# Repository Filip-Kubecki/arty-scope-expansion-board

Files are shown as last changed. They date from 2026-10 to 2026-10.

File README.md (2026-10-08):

<!-- markdownlint-disable MD013 MD060 -->

# Two-Channel Scope Expansion Board for Arty A7

KiCad design of an analog shield for the Digilent Arty A7 100T. The board plugs into the Pmod connectors and, together with the FPGA design, forms a two-channel digital oscilloscope.

<p align="center">
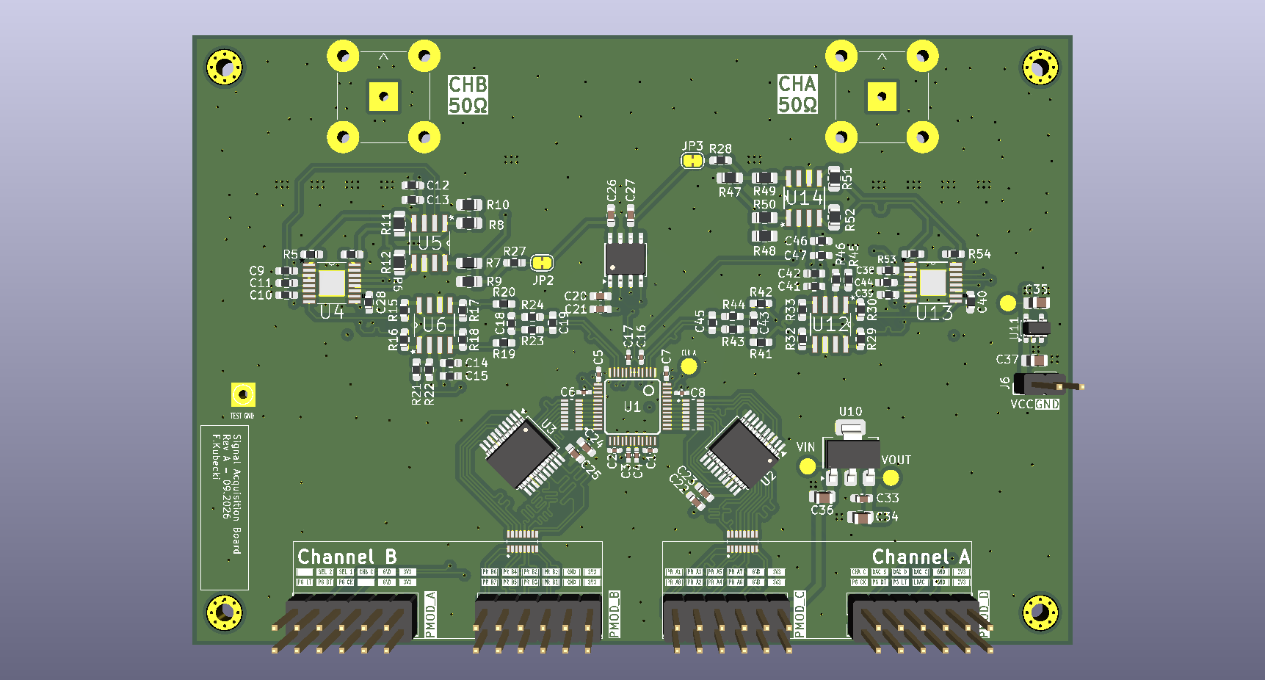
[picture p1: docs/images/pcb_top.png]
3D render of the board
  
</p>

## Hardware

- **Host board:** Digilent Arty A7 100T (connected via Pmod headers)
- **ADC:** AD9288-100 (dual 8-bit, 100 MS/s)
- **PGA:** AD8370 (variable gain amplifier)
- **DAC:** MCP4822 (DC offset)
- **EDA:** KiCad 10.0

## Related repositories

- FPGA design: [arty-scope-hdl](https://github.com/Filip-Kubecki/arty-scope-hdl)

## Repository structure

```
hardware/      KiCad project (schematic, PCB, project-local libraries)
  libs/        custom symbols, footprints and 3D models
docs/          notes, datasheets, pinout and block diagram
fab/           fabrication outputs - Gerbers, drill, BOM, pick&place (git-ignored, see Releases)
```

## Getting started

Clone the repository:

```bash
git clone https://github.com/Filip-Kubecki/arty-scope-expansion-board.git
cd arty-scope-expansion-board
```

Open `hardware/arty-scope-expansion-board.kicad_pro` in KiCad. Project-local libraries are referenced through `sym-lib-table` and `fp-lib-table`, so no manual setup is needed.

### Generating fabrication files

Fabrication outputs are not stored in git. To generate them:

1. Open the PCB in the PCB Editor.
2. Run **File → Fabrication Outputs → Gerbers** and **Drill Files**, writing to `fab/`.
3. Export BOM and placement files from the Schematic and PCB Editors if needed.

Ready-to-order packages for tagged versions are attached to [GitHub Releases](https://github.com/Filip-Kubecki/arty-scope-expansion-board/releases).

## Status

Work in progress.

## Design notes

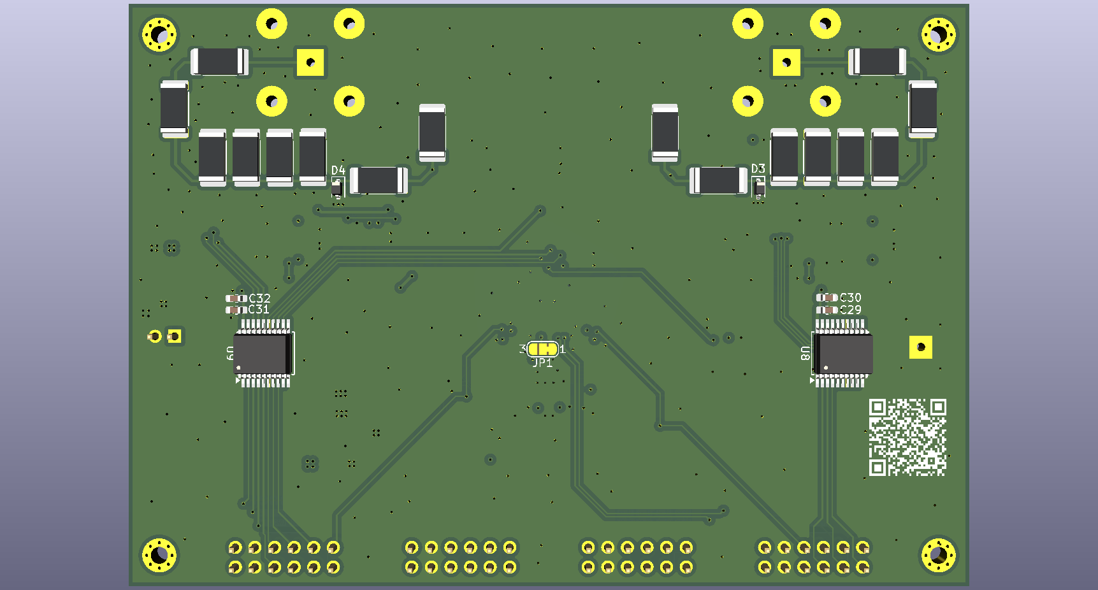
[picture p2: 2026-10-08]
docs/images/pcb_bottom.png

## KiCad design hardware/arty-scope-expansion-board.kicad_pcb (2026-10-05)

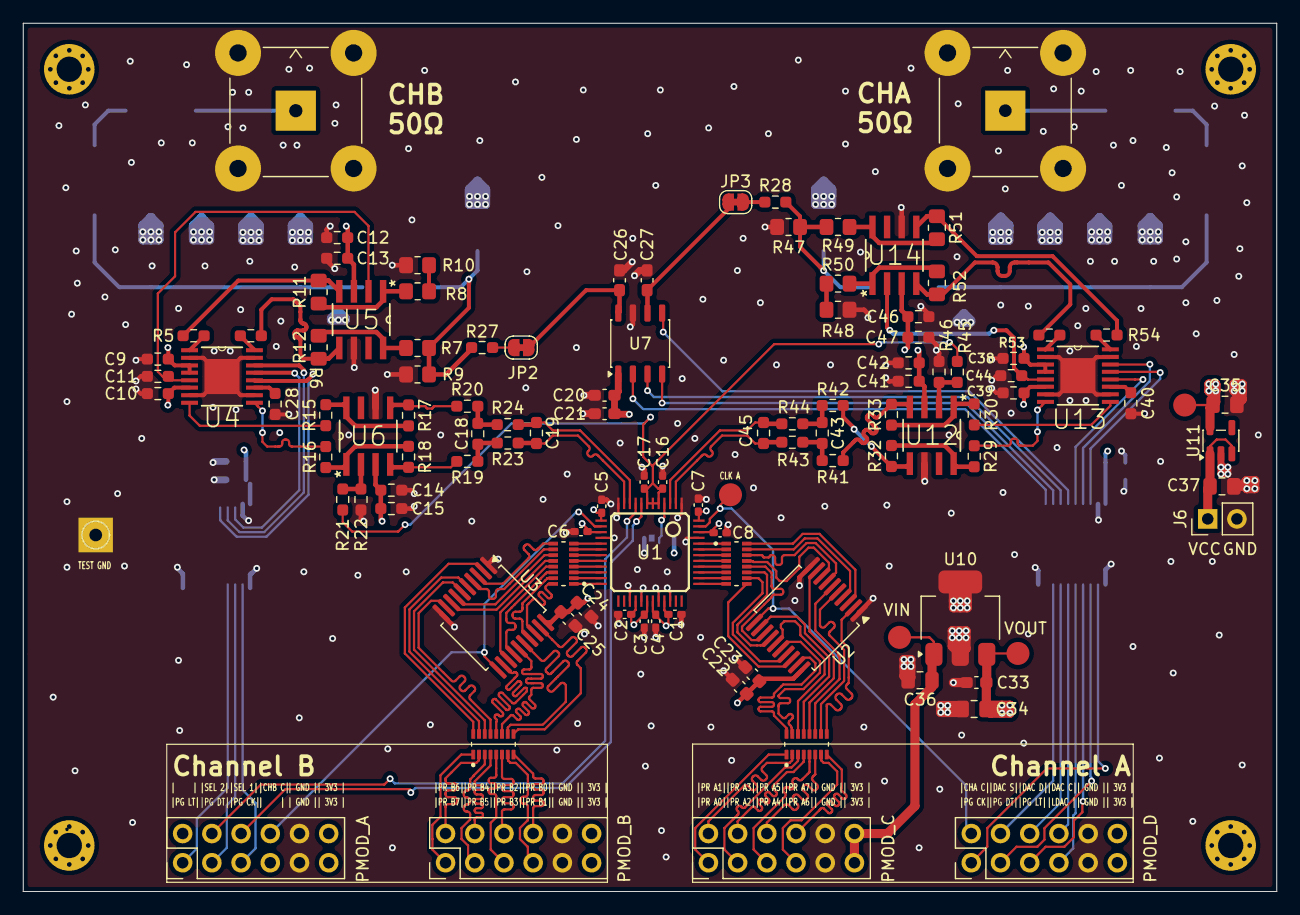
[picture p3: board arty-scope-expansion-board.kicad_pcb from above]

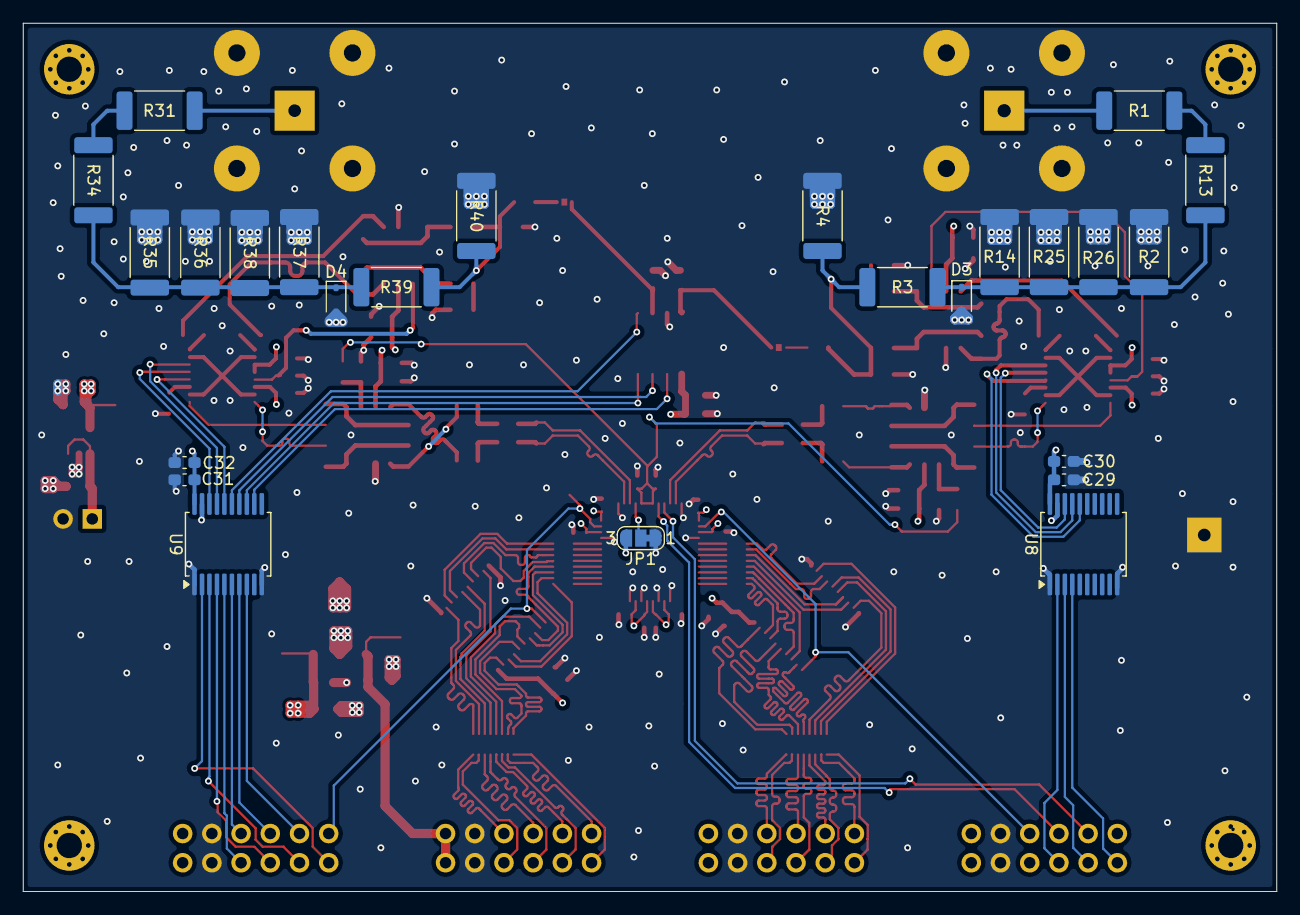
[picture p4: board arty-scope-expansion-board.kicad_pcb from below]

Board: 4 copper layers, 109.0 x 75.5 mm, 131 parts (25 on the bottom side), 147 nets.

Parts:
C1, C2, C3, C4, C5, C6, C7, C8, C16, C17: 100n; C_0402_1005Metric_Pad0.74x0.62mm_HandSolder
C9, C13, C14, C38, C41, C46: 100n; R_0603_1608Metric_Pad0.98x0.95mm_HandSolder
C10, C11, C28, C39, C40, C44: 1n; R_0603_1608Metric_Pad0.98x0.95mm_HandSolder
C12, C15, C42, C47: 10u; R_0603_1608Metric_Pad0.98x0.95mm_HandSolder
C18, C43: 47p; R_0603_1608Metric_Pad0.98x0.95mm_HandSolder
C19, C45: 10p; R_0603_1608Metric_Pad0.98x0.95mm_HandSolder
C20, C23, C25, C29, C31, C33: 100n; C_0603_1608Metric_Pad1.08x0.95mm_HandSolder
C21, C22, C24, C30, C32: 10u; C_0603_1608Metric_Pad1.08x0.95mm_HandSolder
C26, C27: 1n; C_0603_1608Metric_Pad1.08x0.95mm_HandSolder
C34, C35, C37: 1u; C_0805_2012Metric_Pad1.18x1.45mm_HandSolder
C36: 4u7; C_0805_2012Metric_Pad1.18x1.45mm_HandSolder
D3, D4: CDSOD323-T24C; D_SOD-323
J1: PMOD_A; PinHeader_2x06_P2.54mm_Vertical
J2: PMOD_B; PinHeader_2x06_P2.54mm_Vertical
J3: PMOD_C; PinHeader_2x06_P2.54mm_Vertical
J4: PMOD_D; PinHeader_2x06_P2.54mm_Vertical
J5, J7: Conn_Coaxial; BNC_TEConnectivity_1478035_Horizontal
J6: Conn_01x02_Pin; PinHeader_1x02_P2.54mm_Vertical
JP1: DFS Select; SolderJumper-3_P1.3mm_Bridged12_RoundedPad1.0x1.5mm_NumberL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
JP2, JP3: Jumper_2_Bridged; SolderJumper-2_P1.3mm_Bridged_RoundedPad1.0x1.5mm
R1, R13, R31, R34: 11; R_2512_6332Metric_Pad1.40x3.35mm_HandSolder
R2, R14, R25, R26, R35, R36, R37, R38: 222; R_2512_6332Metric_Pad1.40x3.35mm_HandSolder
R3, R39: 499; R_2512_6332Metric_Pad1.40x3.35mm_HandSolder
R4, R40: 55.6; R_2512_6332Metric_Pad1.40x3.35mm_HandSolder
R5, R6, R19, R20, R41, R42, R53, R54: 100; R_0603_1608Metric_Pad0.98x0.95mm_HandSolder
R7, R8, R11, R12, R49, R50, R51, R52: 499; R_0805_2012Metric_Pad1.20x1.40mm_HandSolder
R9, R47: 55.6; R_0805_2012Metric_Pad1.20x1.40mm_HandSolder
R10, R48: 27.8; R_0805_2012Metric_Pad1.20x1.40mm_HandSolder
R15, R16, R17, R18, R29, R30, R32, R33: 499; R_0603_1608Metric_Pad0.98x0.95mm_HandSolder
R21, R45: 2.61k; R_0603_1608Metric_Pad0.98x0.95mm_HandSolder
R22, R46: 10k; R_0603_1608Metric_Pad0.98x0.95mm_HandSolder
R23, R24, R43, R44: 49.9; R_0603_1608Metric_Pad0.98x0.95mm_HandSolder
R27, R28: 20k; R_0603_1608Metric_Pad0.98x0.95mm_HandSolder
R_Pack_ADC_Side_A1: 51; RESCAXE50P380X160X55-16N
R_Pack_ADC_Side_B1: 51; RESCAXE50P380X160X55-16N
R_Pack_PMOD_Side_A1: 51; RESCAXE50P380X160X55-16N
R_Pack_PMOD_Side_B1: 51; RESCAXE50P380X160X55-16N
U1: AD9288; LQFP48
U2, U3: 74LS374; SSOP-20_5.3x7.2mm_P0.65mm
U4, U13: AD8370AREZ-RL7; SOP65P640X120-17N
U5, U6, U12, U14: AD8132ARZ; SOIC127P600X175-8N
U7: MCP4822; JEITA_SOIC-8_3.9x4.9mm_P1.27mm
U8, U9: 74AHCT541; SSOP-20_5.3x7.2mm_P0.65mm
U10: MCP1826S; SOT-223-3_TabPin2
U11: MIC5504-3.3YM5; SOT-23-5

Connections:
+3.3VCC: C1.1, C2.1, C3.1, C4.1, C5.1, C6.1, C7.1, C8.1, C22.1, C23.1, C24.1, C25.1, C33.1, C34.1, JP1.3 (B), U1.13 (VD@1), U1.15 (VDD@1), U1.28 (VDD@2), U1.30 (VD@2), U1.31 (VD@3), U1.33 (VDD@3), U1.46 (VDD@4), U1.48 (VD@4), U2.20 (VCC), U3.20 (VCC), U10.3 (VO)
+5VCC: C9.2, C10.2, C12.2, C13.2, C14.2, C15.2, C20.2, C21.2, C29.2, C30.2, C31.2, C32.2, C35.1, C38.2, C39.2, C41.2, C42.2, C46.2, C47.2, U4.3 (VCCI), U4.4 (PWUP), U4.6 (VCCO_2), U5.3 (V+), U6.3 (V+), U7.1 (Vdd), U8.20 (VCC), U9.20 (VCC), U11.5 (VOUT), U12.3 (V+), U13.3 (VCCI), U13.4 (PWUP), U13.6 (VCCO_2), U14.3 (V+)
/Root/ADC_DATA_A0: R_Pack_ADC_Side_A1.8 (R8.1), U1.37 (D0A)
/Root/ADC_DATA_A1: R_Pack_ADC_Side_A1.7 (R7.1), U1.38 (D1A)
/Root/ADC_DATA_A2: R_Pack_ADC_Side_A1.6 (R6.1), U1.39 (D2A)
/Root/ADC_DATA_A3: R_Pack_ADC_Side_A1.5 (R5.1), U1.40 (D3A)
/Root/ADC_DATA_A4: R_Pack_ADC_Side_A1.4 (R4.1), U1.41 (D4A)
/Root/ADC_DATA_A5: R_Pack_ADC_Side_A1.3 (R3.1), U1.42 (D5A)
/Root/ADC_DATA_A6: R_Pack_ADC_Side_A1.2 (R2.1), U1.43 (D6A)
/Root/ADC_DATA_A7: R_Pack_ADC_Side_A1.1 (R1.1), U1.44 (D7A)
/Root/ADC_DATA_B0: R_Pack_ADC_Side_B1.1 (R1.1), U1.24 (D0B)
/Root/ADC_DATA_B1: R_Pack_ADC_Side_B1.2 (R2.1), U1.23 (D1B)
/Root/ADC_DATA_B2: R_Pack_ADC_Side_B1.3 (R3.1), U1.22 (D2B)
/Root/ADC_DATA_B3: R_Pack_ADC_Side_B1.4 (R4.1), U1.21 (D3B)
/Root/ADC_DATA_B4: R_Pack_ADC_Side_B1.5 (R5.1), U1.20 (D4B)
/Root/ADC_DATA_B5: R_Pack_ADC_Side_B1.6 (R6.1), U1.19 (D5B)
/Root/ADC_DATA_B6: R_Pack_ADC_Side_B1.7 (R7.1), U1.18 (D6B)
/Root/ADC_DATA_B7: R_Pack_ADC_Side_B1.8 (R8.1), U1.17 (D7B)
/Root/DFLOP_ADC_DATA_A0: R_Pack_ADC_Side_A1.9 (R8.2), U2.18 (D7)
/Root/DFLOP_ADC_DATA_A1: R_Pack_ADC_Side_A1.10 (R7.2), U2.17 (D6)
/Root/DFLOP_ADC_DATA_A2: R_Pack_ADC_Side_A1.11 (R6.2), U2.14 (D5)
/Root/DFLOP_ADC_DATA_A3: R_Pack_ADC_Side_A1.12 (R5.2), U2.13 (D4)
/Root/DFLOP_ADC_DATA_A4: R_Pack_ADC_Side_A1.13 (R4.2), U2.8 (D3)
/Root/DFLOP_ADC_DATA_A5: R_Pack_ADC_Side_A1.14 (R3.2), U2.7 (D2)
/Root/DFLOP_ADC_DATA_A6: R_Pack_ADC_Side_A1.15 (R2.2), U2.4 (D1)
/Root/DFLOP_ADC_DATA_A7: R_Pack_ADC_Side_A1.16 (R1.2), U2.3 (D0)
/Root/DFLOP_ADC_DATA_B0: R_Pack_ADC_Side_B1.16 (R1.2), U3.18 (D7)
/Root/DFLOP_ADC_DATA_B1: R_Pack_ADC_Side_B1.15 (R2.2), U3.17 (D6)
/Root/DFLOP_ADC_DATA_B2: R_Pack_ADC_Side_B1.14 (R3.2), U3.14 (D5)
/Root/DFLOP_ADC_DATA_B3: R_Pack_ADC_Side_B1.13 (R4.2), U3.13 (D4)
/Root/DFLOP_ADC_DATA_B4: R_Pack_ADC_Side_B1.12 (R5.2), U3.8 (D3)
/Root/DFLOP_ADC_DATA_B5: R_Pack_ADC_Side_B1.11 (R6.2), U3.7 (D2)
/Root/DFLOP_ADC_DATA_B6: R_Pack_ADC_Side_B1.10 (R7.2), U3.4 (D1)
/Root/DFLOP_ADC_DATA_B7: R_Pack_ADC_Side_B1.9 (R8.2), U3.3 (D0)
/Root/DFLOP_PMOD_DATA_A0: R_Pack_PMOD_Side_A1.16 (R1.2), U2.19 (O7)
/Root/DFLOP_PMOD_DATA_A1: R_Pack_PMOD_Side_A1.15 (R2.2), U2.16 (O6)
/Root/DFLOP_PMOD_DATA_A2: R_Pack_PMOD_Side_A1.14 (R3.2), U2.15 (O5)
/Root/DFLOP_PMOD_DATA_A3: R_Pack_PMOD_Side_A1.13 (R4.2), U2.12 (O4)
/Root/DFLOP_PMOD_DATA_A4: R_Pack_PMOD_Side_A1.12 (R5.2), U2.9 (O3)
/Root/DFLOP_PMOD_DATA_A5: R_Pack_PMOD_Side_A1.11 (R6.2), U2.6 (O2)
/Root/DFLOP_PMOD_DATA_A6: R_Pack_PMOD_Side_A1.10 (R7.2), U2.5 (O1)
/Root/DFLOP_PMOD_DATA_A7: R_Pack_PMOD_Side_A1.9 (R8.2), U2.2 (O0)
/Root/DFLOP_PMOD_DATA_B0: R_Pack_PMOD_Side_B1.9 (R8.2), U3.19 (O7)
/Root/DFLOP_PMOD_DATA_B1: R_Pack_PMOD_Side_B1.10 (R7.2), U3.16 (O6)
/Root/DFLOP_PMOD_DATA_B2: R_Pack_PMOD_Side_B1.11 (R6.2), U3.15 (O5)
/Root/DFLOP_PMOD_DATA_B3: R_Pack_PMOD_Side_B1.12 (R5.2), U3.12 (O4)
/Root/DFLOP_PMOD_DATA_B4: R_Pack_PMOD_Side_B1.13 (R4.2), U3.9 (O3)
/Root/DFLOP_PMOD_DATA_B5: R_Pack_PMOD_Side_B1.14 (R3.2), U3.6 (O2)
/Root/DFLOP_PMOD_DATA_B6: R_Pack_PMOD_Side_B1.15 (R2.2), U3.5 (O1)
/Root/DFLOP_PMOD_DATA_B7: R_Pack_PMOD_Side_B1.16 (R1.2), U3.2 (O0)
/Root/PMOD_DATA_A0: J3.1, R_Pack_PMOD_Side_A1.1 (R1.1)
/Root/PMOD_DATA_A1: J3.2, R_Pack_PMOD_Side_A1.2 (R2.1)
/Root/PMOD_DATA_A2: J3.3, R_Pack_PMOD_Side_A1.3 (R3.1)
/Root/PMOD_DATA_A3: J3.4, R_Pack_PMOD_Side_A1.4 (R4.1)
/Root/PMOD_DATA_A4: J3.5, R_Pack_PMOD_Side_A1.5 (R5.1)
/Root/PMOD_DATA_A5: J3.6, R_Pack_PMOD_Side_A1.6 (R6.1)
/Root/PMOD_DATA_A6: J3.7, R_Pack_PMOD_Side_A1.7 (R7.1)
/Root/PMOD_DATA_A7: J3.8, R_Pack_PMOD_Side_A1.8 (R8.1)
/Root/PMOD_DATA_B0: J2.8, R_Pack_PMOD_Side_B1.8 (R8.1)
/Root/PMOD_DATA_B1: J2.7, R_Pack_PMOD_Side_B1.7 (R7.1)
/Root/PMOD_DATA_B2: J2.6, R_Pack_PMOD_Side_B1.6 (R6.1)
/Root/PMOD_DATA_B3: J2.5, R_Pack_PMOD_Side_B1.5 (R5.1)
/Root/PMOD_DATA_B4: J2.4, R_Pack_PMOD_Side_B1.4 (R4.1)
/Root/PMOD_DATA_B5: J2.3, R_Pack_PMOD_Side_B1.3 (R3.1)
/Root/PMOD_DATA_B6: J2.2, R_Pack_PMOD_Side_B1.2 (R2.1)
/Root/PMOD_DATA_B7: J2.1, R_Pack_PMOD_Side_B1.1 (R1.1)
AINA+: C19.2, R23.2, U1.11 (AINB)
AINA-: C19.1, R24.2, U1.10 (/AINB)
AINB+: C45.2, R43.2, U1.2 (AINA)
AINB-: C45.1, R44.2, U1.3 (/AINA)
CH_A_CLK: J4.2, U1.47 (ENCA), U2.11 (Cp)
CH_B_CLK: J1.8, U1.14 (ENCB), U3.11 (Cp)
DAC_A: R3.1, R4.1, R7.1, R9.2, R27.1
DAC_B: R28.1, R39.1, R40.1, R47.2, R49.1
DAC_CS_3.3V: J4.4, U9.8 (A6)
DAC_CS_5V: U7.2 (~CS), U9.12 (Y6)
DAC_LDAC_3.3V: J4.7, U9.5 (A3)
DAC_LDAC_5V: U7.5 (~LDAC), U9.15 (Y3)
DAC_SCK_3.3V: J4.8, U9.6 (A4)
DAC_SCK_5V: U7.3 (SCK), U9.14 (Y4)
DAC_SDI_3.3V: J4.6, U9.7 (A5)
DAC_SDI_5V: U7.4 (SDI), U9.13 (Y5)
GND: C1.2, C2.2, C3.2, C4.2, C5.2, C6.2, C7.2, C8.2, C9.1, C10.1, C11.1, C12.1, C13.1, C14.1, C15.1, C16.1, C17.1, C20.1, C21.1, C22.2, C23.2, C24.2, C25.2, C26.2, C27.2, C28.1, C29.1, C30.1, C31.1, C32.1, C33.2, C34.2, C35.2, C36.2, C37.2, C38.1, C39.1, C40.1, C41.1, C42.1, C44.1, C46.1, C47.1, D3.2 (A2), D4.2 (A2), J1.9, J1.10, J2.9, J2.10, J3.9, J3.10, J4.9, J4.10, J5.2 (Ext), J6.2, J7.2 (Ext), JP1.1 (A), R2.2, R4.2, R9.1, R10.1, R14.2, R22.1, R25.2, R26.2, R35.2, R36.2, R37.2, R38.2, R40.2, R46.1, R47.1, R48.1, U1.1 (GND@1), U1.12 (GND@2), U1.16 (GND@3), U1.27 (GND@4), U1.29 (GND@5), U1.32 (GND@6), U1.34 (GND@7), U1.45 (GND@8), U2.1 (OE), U2.10 (GND), U3.1 (OE), U3.10 (GND), U4.2 (ICOM_2), U4.7 (OCOM_2), U4.10 (OCOM), U4.15 (ICOM), U4.17 (EP), U5.6 (V-), U6.6 (V-), U7.7 (Vss), U8.1 (G1), U8.10 (GND), U8.19 (G2), U9.1 (G1), U9.10 (GND), U9.19 (G2), U10.2 (GND), U11.2 (GND), U12.6 (V-), U13.2 (ICOM_2), U13.7 (OCOM_2), U13.10 (OCOM), U13.15 (ICOM), U13.17 (EP), U14.6 (V-)
INHI_A: R5.2, U4.1 (INHI)
INHI_B: R53.2, U13.1 (INHI)
INLO_A: R6.2, U4.16 (INLO)
INLO_B: R54.2, U13.16 (INLO)
unnamed: C18.1, R20.2, R24.1
unnamed: C18.2, R19.2, R23.1
unnamed: C43.1, R42.2, R44.1
unnamed: C43.2, R41.2, R43.1
unnamed: D3.1 (A1), R2.1, R3.2, R13.1, R14.1, R25.1, R26.1
unnamed: D4.1 (A1), R34.1, R35.1, R36.1, R37.1, R38.1, R39.2
unnamed: J5.1 (In), R1.2
unnamed: C37.1, J6.1, U11.1 (VIN), U11.3 (EN)
unnamed: J7.1 (In), R31.2
unnamed: JP1.2 (C), U1.4 (DFS)
unnamed: C26.1, JP2.1 (A), U7.8 (VA)
unnamed: JP2.2 (B), R27.2
unnamed: C27.1, JP3.1 (A), U7.6 (VB)
unnamed: JP3.2 (B), R28.2
unnamed: R1.1, R13.2
unnamed: R8.1, R10.2
unnamed: R31.1, R34.2
unnamed: R48.2, R50.1
unnamed: C28.2, U4.11 (VCCO)
unnamed: R7.2, R12.2, U5.8 (+IN)
unnamed: R5.1, R11.2, U5.4 (+OUT)
unnamed: R8.2, R11.1, U5.1 (-IN)
unnamed: R6.1, R12.1, U5.5 (-OUT)
unnamed: R15.2, R17.2, U6.8 (+IN)
unnamed: R18.2, R19.1, U6.4 (+OUT)
unnamed: R16.2, R18.1, U6.1 (-IN)
unnamed: R17.1, R20.1, U6.5 (-OUT)
unnamed: R29.2, R32.2, U12.8 (+IN)
unnamed: R33.2, R41.1, U12.4 (+OUT)
unnamed: R30.2, R33.1, U12.1 (-IN)
unnamed: R32.1, R42.1, U12.5 (-OUT)
unnamed: C40.2, U13.11 (VCCO)
unnamed: R49.2, R51.2, U14.8 (+IN)
unnamed: R52.2, R53.1, U14.4 (+OUT)
unnamed: R50.2, R52.1, U14.1 (-IN)
unnamed: R51.1, R54.1, U14.5 (-OUT)
OP_A+: R15.1, U4.8 (OPHI)
OP_A-: R16.1, U4.9 (OPLO)
OP_B+: R29.1, U13.8 (OPHI)
OP_B-: R30.1, U13.9 (OPLO)
PGA_CLK_A_3.3V: J1.5, U8.2 (A0)
PGA_CLK_A_5V: U4.13 (CLCK), U8.18 (Y0)
PGA_CLK_B_3.3V: J4.1, U9.2 (A0)
PGA_CLK_B_5V: U9.18 (Y0), U13.13 (CLCK)
PGA_DATA_A_3.3V: J1.3, U8.3 (A1)
PGA_DATA_A_5V: U4.14 (DATA), U8.17 (Y1)
PGA_DATA_B_3.3V: J4.3, U9.3 (A1)
PGA_DATA_B_5V: U9.17 (Y1), U13.14 (DATA)
PGA_LATCH_A_3.3V: J1.1, U8.4 (A2)
PGA_LATCH_A_5V: U4.12 (LTCH), U8.16 (Y2)
PGA_LATCH_B_3.3V: J4.5, U9.4 (A2)
PGA_LATCH_B_5V: U9.16 (Y2), U13.12 (LTCH)
REFOUT: C16.2, C17.2, R21.2, R45.2, U1.5 (REFINA), U1.6 (REFOUT), U1.7 (REFINB)
REFOUT_VOCM_A: R21.1, R22.2, U6.2 (VOCM)
REFOUT_VOCM_B: R45.1, R46.2, U12.2 (VOCM)
SEL1: J1.6, U1.8 (S1)
SEL2: J1.4, U1.9 (S2)
VIN_3.3V: C36.1, J3.11, J3.12, U10.1 (VI)
VOCM_A: C11.2, U4.5 (VOCM), U5.2 (VOCM)
VOCM_B: C44.2, U13.5 (VOCM), U14.2 (VOCM)

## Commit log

2026-08-25 [feat] Added digital part of the device (logical and schematic)
    Not tested yet - may contain bugs.
    [arty-scope-expansion-board.kicad_pcb, arty-scope-expansion-board.kicad_sch, digital.kicad_sch]
2026-08-26 [backup] Recent small changes
    [arty-scope-expansion-board.kicad_sch]
2026-09-01 [feat] Added part of A channel analog input stage
    Rough signal chain, not final:
    - BNC (50R)
    - overvoltage protection (series R + TVS, 40Vpp)
    - fixed pi attenuator -26dB (55.6R / 499R)
    - AD8132 as single-ended-to-diff level shifter (DC-coupled, VOCM 2.5V)
    - AD8370 VGA (SPI, dual gain range)
    TODO: anti-aliasing filter, output driver stage, offset trim DAC
    [arty-scope-expansion-board.kicad_sch]
2026-09-02 [feat] Added next part of A channel analog input stage
    Some updates:
    - driver stage for ADC input A
    - correction in input protection stage
    - added filtering on VCC of analog stage IC's
    [arty-scope-expansion-board.kicad_sch]
2026-09-05 [feat] Added footprints to all A channel elements
    TVS diode still doesn't have correct footprint or model. Find one on
    LCSC.
    [arty-scope-expansion-board.kicad_pcb, arty-scope-expansion-board.kicad_sch]
2026-09-06 [feat] Started routing A channel input traces
    Input 50 Ohm traces still needs routing. Anty aliasing filter needs
    checking if values are correct with some simulation software. Still no
    power planes. Serial signals for PGA/VGA and DAC needs logic level
    shifters from 3.3V FPGA to 5V signals.
    [arty-scope-expansion-board.kicad_pcb, arty-scope-expansion-board.kicad_sch]
2026-09-14 [feat] Added power planes with LDO's and changed footprints to correct ones
    Two power planes where added:
    - 3.3V powered by Arty via LDO
    - 5V powered via gpio via LDO (can be powered by Arty 5V - i think)
    Changed smaller capacitors sizes to correct ones. In prevous iterations
    i missmached metric footprints with imperial ones.
    Rerouted whole input stage.
    [arty-scope-expansion-board.kicad_pcb, arty-scope-expansion-board.kicad_sch]
2026-09-15 [feat] Added second channel with routing
    [arty-scope-expansion-board.kicad_pcb, arty-scope-expansion-board.kicad_sch]
2026-09-15 [feat] Added ground planes on top and bottom layers
    Also connected ref voltage to driver op amp
2026-09-15 [feat] Changed input stage routing, corrected DRC errors, added some silk labels
    [arty-scope-expansion-board.kicad_pcb, arty-scope-expansion-board.kicad_sch, digital.kicad_sch]
2026-09-30 [backup] ---
    [arty-scope-expansion-board.kicad_pcb, digital.kicad_sch]
2026-09-30 [feat] Added stitching vias and filled top and bottom with ground
    [arty-scope-expansion-board.kicad_pcb]
2026-10-04 [feat] Added test points and some labels on silkscreen
    [arty-scope-expansion-board.kicad_pcb]
2026-10-05 [feat] Repaired some silkscreen errors and added some labels
    [arty-scope-expansion-board.kicad_pcb]
2026-10-08 Restructure repo: move KiCad project to hardware/, ignore generated files, added README.md
    [arty-scope-expansion-board.kicad_pcb, arty-scope-expansion-board.kicad_sch, digital.kicad_sch]
2026-10-08 Add top and bottom board renders to README
2026-10-08 Change image source for board top render
    Updated image source for board render in README.
2026-11-05 Add versioning to PCB image in README
    Updated image source in README to include versioning.
